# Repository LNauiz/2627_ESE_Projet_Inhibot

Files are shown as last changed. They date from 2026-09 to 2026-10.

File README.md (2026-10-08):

# 2627_ESE_Projet_Inhibot
_Projet réalisé par SERPHIN Bradley, NAVIZET Léonard et BOISBOURDIN Lucas_

---
## Présentation du projet
Le but du projet est de créer un petit robot autonome capable de récupérer des canettes en fonction de leur couleur, par exemple rouge ou verte, et de déposer ces canettes dans une zone définis à l'avance.

Architecture du projet :

Micro Controller

---

## Plan de la présentation
* [Conception du PCB](#conception-du-pcb)
* [Mécanique du robot](#mecanique-du-robot)
* [Code](#code)

---
## Conception du PCB
Pour la conception du PCB, plusieurs composants étaient recommandés :

- [Régulateur de tension 3.3V (BU)](https://github.com/LNauiz/2627_ESE_Projet_Inhibot/blob/main/Datasheet/Regulateur3-3V_buxxsd5wg-e.pdf)
- [Chargeur de batterie (BQ25896RTWR)](https://github.com/LNauiz/2627_ESE_Projet_Inhibot/blob/main/Datasheet/bq25896.pdf)
- [Jauge pour la batterie (BQ27220)](https://github.com/LNauiz/2627_ESE_Projet_Inhibot/blob/main/Datasheet/bq27220.pdf)
- [Driver de moteur (DRV8833PWR)](https://github.com/LNauiz/2627_ESE_Projet_Inhibot/blob/main/Datasheet/DriverMotoreducteur_drv8833.pdf)

En plus de ces composants recommandés nous avons ajouté les composants suivant :
- [STM32G431RBT6](https://github.com/LNauiz/2627_ESE_Projet_Inhibot/blob/main/Datasheet/stm32g431rbt6.pdf)
- [Accéléromètre et Gyroscope (LSM6DSLTR)](https://github.com/LNauiz/2627_ESE_Projet_Inhibot/blob/main/Datasheet/Accelerometre%26Gyroscope_LSM6DSLTR.pdf)

---
## Mécanique du robot
Pour réaliser la partie mécanique il fallait savoir quelle format de canette le robot doit récupérer. Le format choisis est le format "Sleek".

---
## Code

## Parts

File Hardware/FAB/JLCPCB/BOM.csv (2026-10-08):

Comment | Designator | Footprint | JLCPCB Part #
10pF | C202,C203 | Capacitor_SMD:C_0402_1005Metric | C32949
10n | C207,C403 | Capacitor_SMD:C_0402_1005Metric | C15195
47n | C304 | Capacitor_SMD:C_0402_1005Metric | C880605
100n | C201,C204,C205,C206,C209,C210,C301,C401,C402,C502,C503,C505,C506,C507,C508,C509,C510 | Capacitor_SMD:C_0402_1005Metric | C1525
470n | C302 | Capacitor_SMD:C_0603_1608Metric | C1623
1u | C311,C312,C314,C501,C504 | Capacitor_SMD:C_0402_1005Metric | C52923
1u | L301 |  | C84468
2.2u | C303,C404 | Capacitor_SMD:C_0402_1005Metric | C12530
4u7 | C208,C305 | Capacitor_SMD:C_0402_1005Metric | C23733
8.2u | C310 | Capacitor_SMD:C_1206_3216Metric | C2182568
10u | C306,C307,C308,C309,C405 | Capacitor_SMD:C_0402_1005Metric | C15525
470u | C406 | Capacitor_SMD:CP_Elec_10x10.5 | C178566
10m | R306 | Resistor_SMD:R_2512_6332Metric | C105142
200m | R404,R407 | Resistor_SMD:R_0805_2012Metric | C2074761
100 | R314 | Resistor_SMD:R_0402_1005Metric | C25076
470R | R308 | Resistor_SMD:R_0402_1005Metric | C25117
1k | R202,R203,R305,R401,R402,R403,R405,R406 | Resistor_SMD:R_0402_1005Metric | C11702
4.7k | R207,R208,R317 | Resistor_SMD:R_0402_1005Metric | C25900
5k1 | R302,R303,R312,R313 | Resistor_SMD:R_0402_1005Metric | C25905
10k | R307,R309,R310,R311,R315,R316,R408 | Resistor_SMD:R_0402_1005Metric | C25744
100k | R301,R304 | Resistor_SMD:R_0402_1005Metric | C25741
BQ25896RTWR | U302 | Package_DFN_QFN:Texas_RTW_WQFN-24-1EP_4x4mm_P0.5mm_EP2.7x2.7mm | C181475
BQ27220YZFR | U303 | Package_BGA:Texas_DSBGA-9_1.4715x1.4715mm_Layout3x3_P0.5mm | C528617
BU33SD5WG-TR | U305 | Package_TO_SOT_SMD:TSOT-23-5 | C3750265
Conn_ST_STDC14 | J201 | Connector_PinHeader_1.27mm:PinHeader_2x07_P1.27mm_Vertical_SMD | C3975190
DMN313DLT-7 | Q303 | Package_TO_SOT_SMD:SOT-523 | C155524
DMP1045U-7 | Q302 | Package_TO_SOT_SMD:SOT-23 | C177033
DRV8833PW-PR | U402 | Package_SO:TSSOP-16-1EP_4.4x5mm_P0.65mm_EP3x3mm | C50506
GREEN | D201 | LED_SMD:LED_0603_1608Metric | C12624
LSM6DSL | U401 | Package_LGA:LGA-14_3x2.5mm_P0.5mm_LayoutBorder3x4y | C126672
MMDT2222A | Q301 | Package_TO_SOT_SMD:SOT-363_SC-70-6 | C7603394
RED | D202 | LED_SMD:LED_0603_1608Metric | C2286
SN74AHCT1G125DBVR | U501 | Package_TO_SOT_SMD:SOT-23-5 | C20617903
STAT | D303 | LED_SMD:LED_0603_1608Metric | C111340
STM32G431RBT6 | U201 | Package_QFP:LQFP-64_10x10mm_P0.5mm | C431633
SW_Push | SW101,SW201 | Button_Switch_SMD:SW_Push_1P1T_NO_CK_KMR2 | C72443
USB_C_Receptacle_USB2.0_16P | J301 | Connector_USB:USB_C_Receptacle_GCT_USB4105-xx-A_16P_TopMnt_Horizontal | C2765186
USBLC6-2SC6 | U301 | Package_TO_SOT_SMD:SOT-23-6 | C7519
WS2812B | D502 | LED_SMD:LED_WS2812B-Mini_PLCC4_3.5x3.5mm | C52941386
X322516MLB4SI | Y201 | Crystal:Crystal_SMD_EuroQuartz_MT-4Pin_3.2x2.5mm | C13738
~{PG} | D302 | LED_SMD:LED_0603_1608Metric | C12624

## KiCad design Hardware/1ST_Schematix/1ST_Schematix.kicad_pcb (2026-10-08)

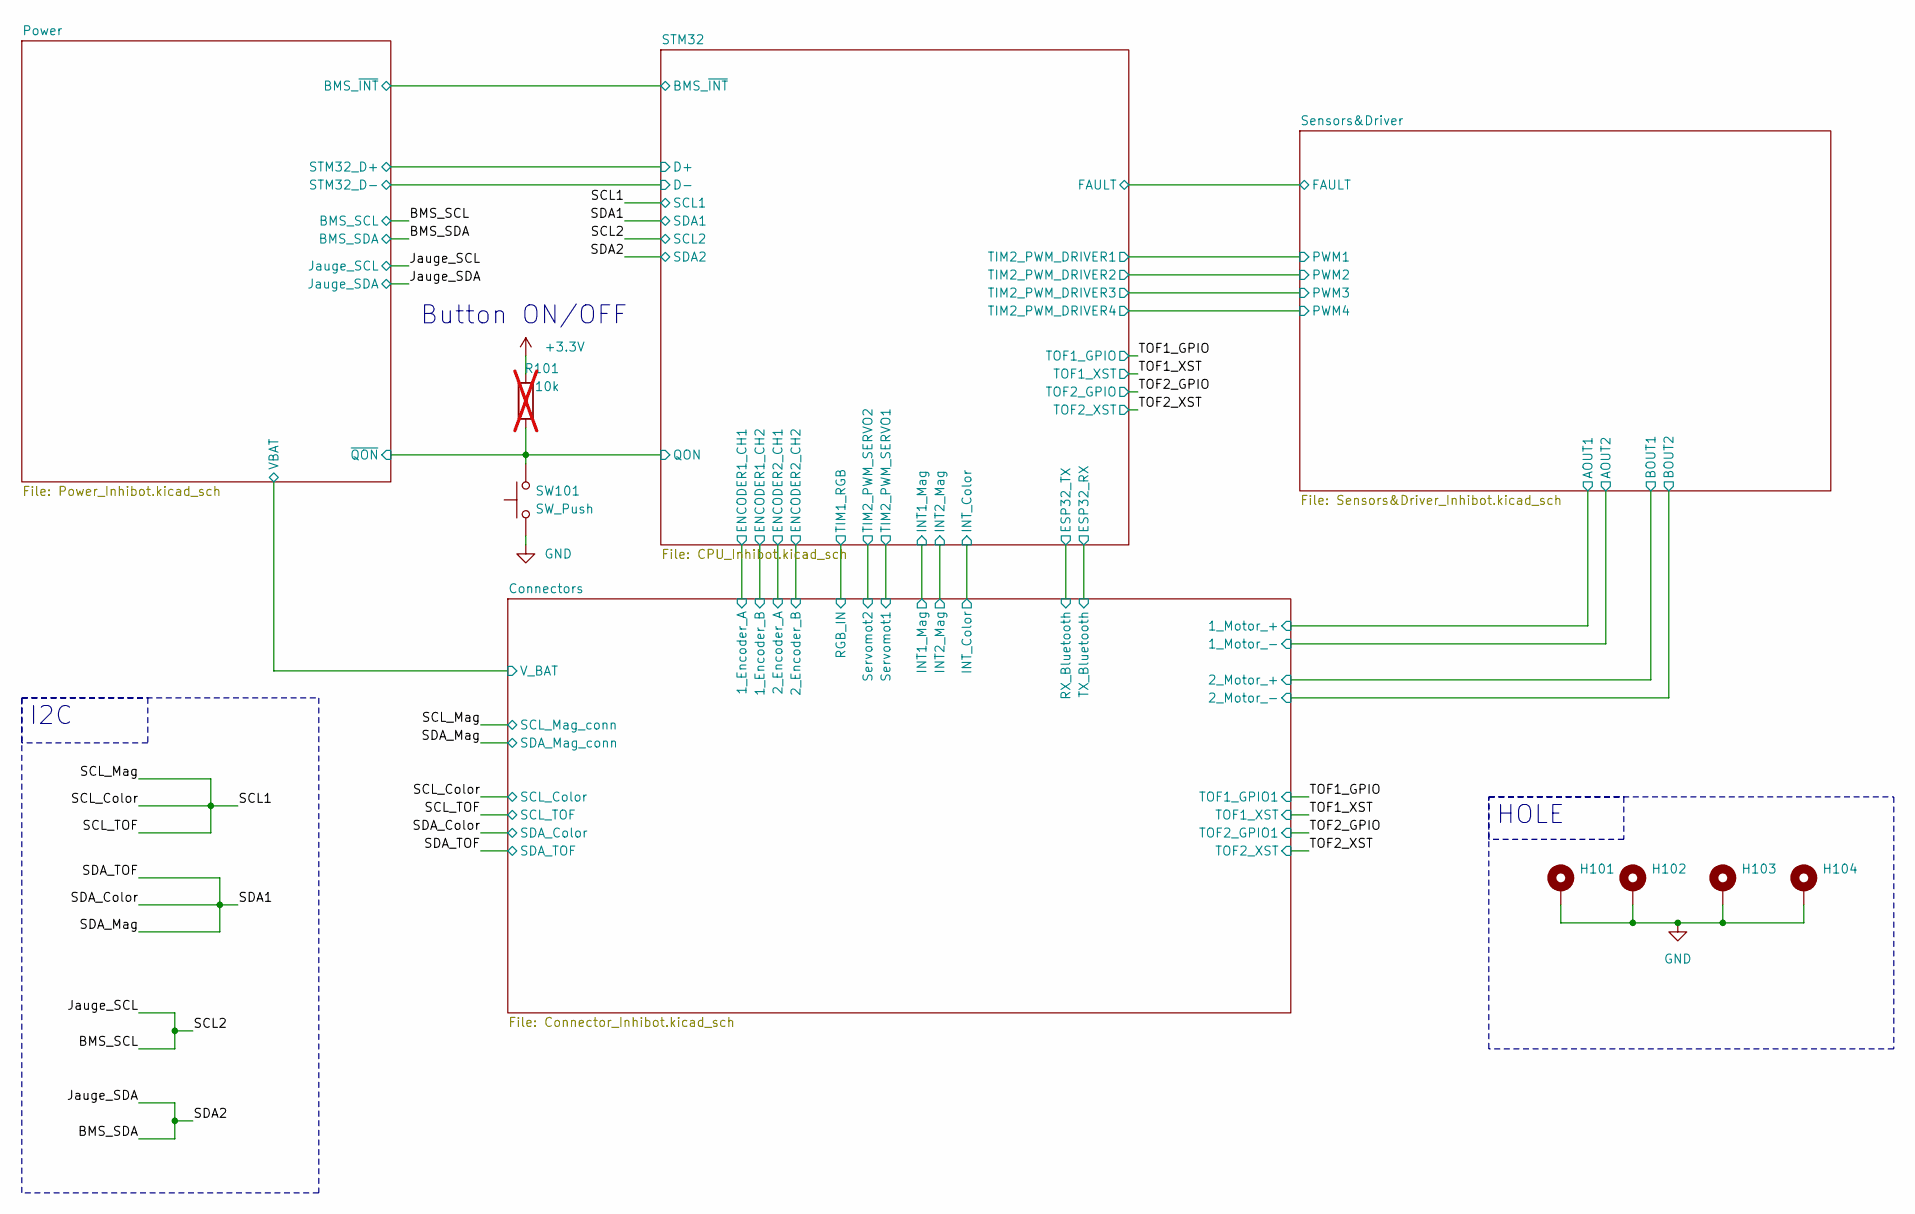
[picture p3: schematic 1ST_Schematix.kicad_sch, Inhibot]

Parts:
H101, H102, H103, H104: MountingHole_Pad; MountingHole_3.2mm_M3_ISO14580_Pad
R101: 10k; R_0603_1608Metric_Pad0.98x0.95mm_HandSolder; not fitted
SW101: SW_Push; SW_Push_1P1T_NO_CK_KMR2; JLCPCB Parts # C72443

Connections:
+3.3V: R101.1; also elsewhere on the board
/Power/~QON: R101.2, SW101.2; also elsewhere on the board
GND: H101.1 (1_1), H102.1 (1_1), H103.1 (1_1), H104.1 (1_1), SW101.1; also elsewhere on the board

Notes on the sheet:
Button ON/OFF
I2C
HOLE

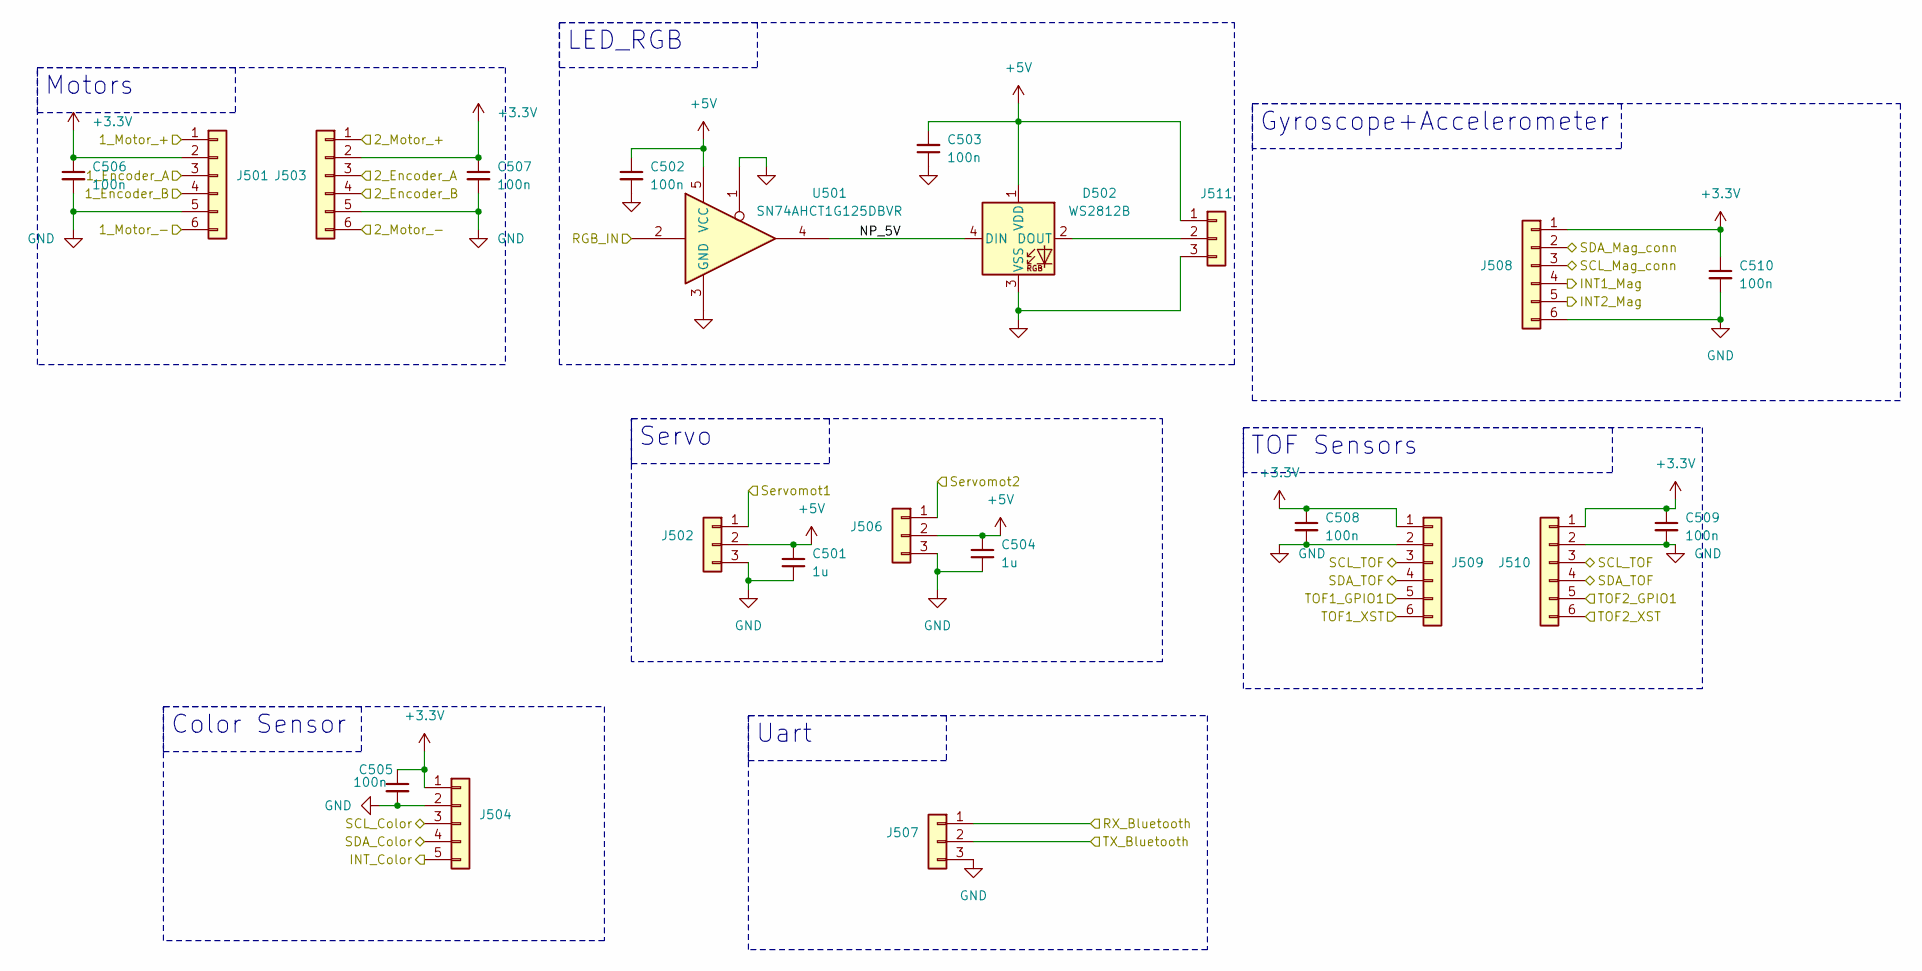
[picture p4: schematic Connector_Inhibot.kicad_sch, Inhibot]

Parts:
C501, C504: 1u; C_0402_1005Metric; JLCPCB Parts # C52923
C502, C503, C505, C506, C507, C508, C509, C510: 100n; C_0402_1005Metric; JLCPCB Parts # C1525
D502: WS2812B; LED_WS2812B-Mini_PLCC4_3.5x3.5mm; JLCPCB Parts # C52941386
J501, J503, J508, J509, J510: Conn_01x06; JST_EH_B6B-EH-A_1x06_P2.50mm_Vertical
J502, J506, J507, J511: Conn_01x03; JST_EH_B3B-EH-A_1x03_P2.50mm_Vertical
J504: Conn_01x05; JST_EH_B5B-EH-A_1x05_P2.50mm_Vertical
U501: SN74AHCT1G125DBVR; SOT-23-5; JLCPCB Parts # C20617903

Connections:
+3.3V: C505.1, C506.1, C507.1, C508.1, C509.1, C510.1, J501.2, J503.2, J504.1, J508.1, J509.1, J510.1; also elsewhere on the board
+5V: C501.1, C502.1, C503.2, C504.1, D502.1 (VDD), J502.2, J506.2, J511.1, U501.5 (VCC); also elsewhere on the board
/Connectors/1_Encoder_A: J501.3; also elsewhere on the board
/Connectors/1_Encoder_B: J501.4; also elsewhere on the board
/Connectors/1_Motor_+: J501.1; also elsewhere on the board
/Connectors/1_Motor_-: J501.6; also elsewhere on the board
/Connectors/2_Encoder_A: J503.3; also elsewhere on the board
/Connectors/2_Encoder_B: J503.4; also elsewhere on the board
/Connectors/2_Motor_+: J503.1; also elsewhere on the board
/Connectors/2_Motor_-: J503.6; also elsewhere on the board
/Connectors/INT1_Mag: J508.4; also elsewhere on the board
/Connectors/INT2_Mag: J508.5; also elsewhere on the board
/Connectors/INT_Color: J504.5; also elsewhere on the board
/Connectors/NP_5V: D502.4 (DIN), U501.4
/Connectors/RGB_IN: U501.2; also elsewhere on the board
/Connectors/RX_Bluetooth: J507.1; also elsewhere on the board
/Connectors/Servomot1: J502.1; also elsewhere on the board
/Connectors/Servomot2: J506.1; also elsewhere on the board
/Connectors/TX_Bluetooth: J507.2; also elsewhere on the board
/SCL1: J504.3, J508.3, J509.3, J510.3; also elsewhere on the board
/SDA1: J504.4, J508.2, J509.4, J510.4; also elsewhere on the board
/TOF1_GPIO: J509.5; also elsewhere on the board
/TOF1_XST: J509.6; also elsewhere on the board
/TOF2_GPIO: J510.5; also elsewhere on the board
/TOF2_XST: J510.6; also elsewhere on the board
GND: C501.2, C502.2, C503.1, C504.2, C505.2, C506.2, C507.2, C508.2, C509.2, C510.2, D502.3 (VSS), J501.5, J502.3, J503.5, J504.2, J506.3, J507.3, J508.6, J509.2, J510.2, J511.3, U501.1, U501.3 (GND); also elsewhere on the board
unnamed: D502.2 (DOUT), J511.2

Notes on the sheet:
Uart
LED_RGB
Servo
TOF Sensors
Color Sensor
Gyroscope+Accelerometer
Motors

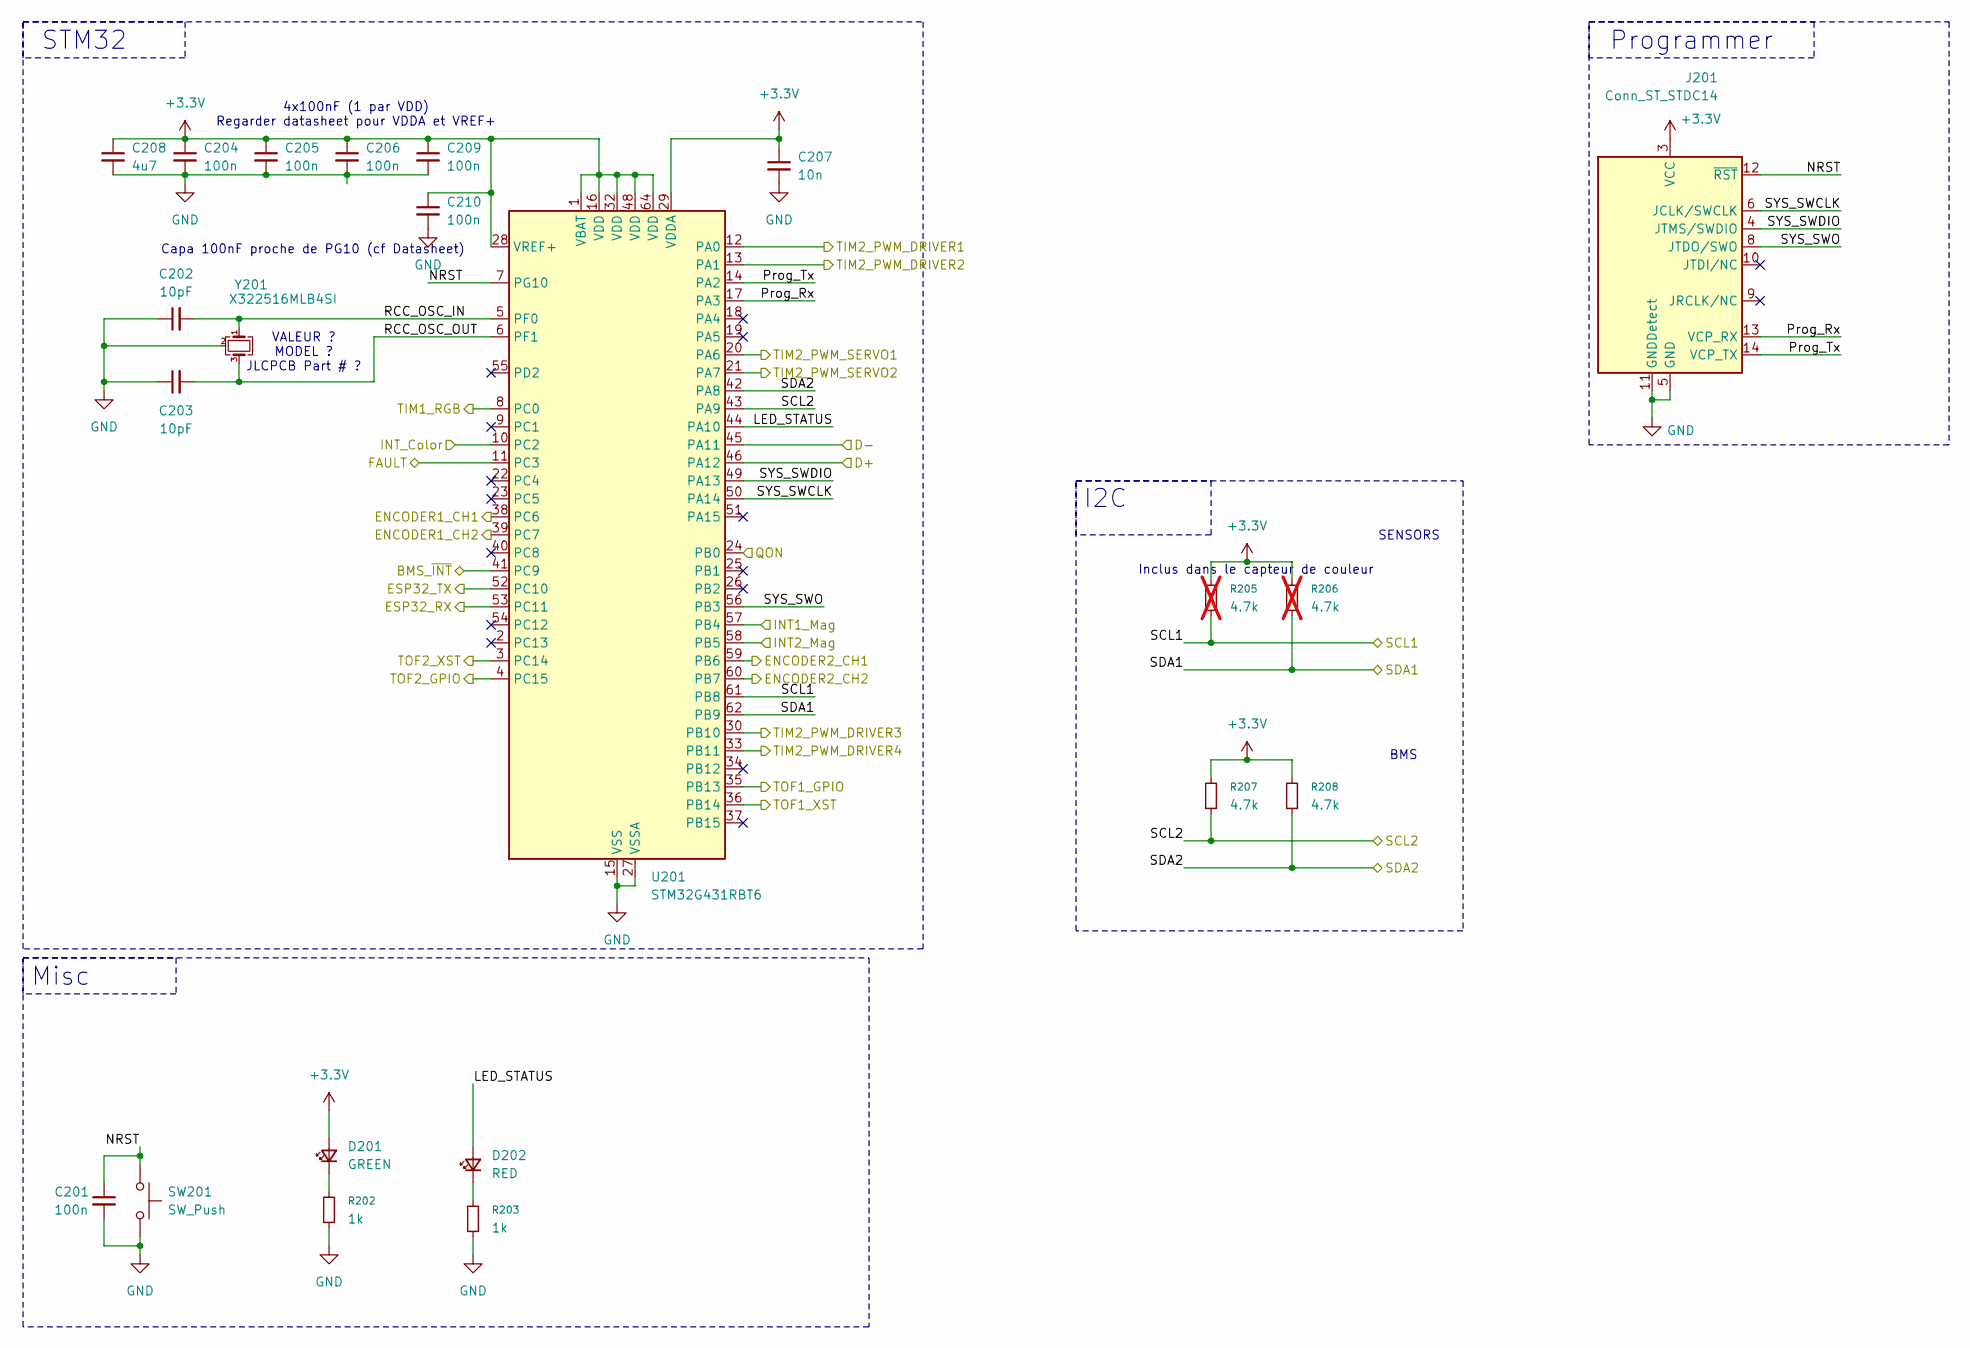
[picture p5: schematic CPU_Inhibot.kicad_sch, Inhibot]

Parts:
C201, C204, C205, C206, C209, C210: 100n; C_0402_1005Metric; JLCPCB Parts # C1525
C202, C203: 10pF; C_0402_1005Metric; JLCPCB Parts # C32949
C207: 10n; C_0402_1005Metric; JLCPCB Parts # C15195
C208: 4u7; C_0402_1005Metric; JLCPCB Parts # C23733
D201: GREEN; LED_0603_1608Metric; JLCPCB Parts # C12624
D202: RED; LED_0603_1608Metric; JLCPCB Parts # C2286
J201: Conn_ST_STDC14; PinHeader_2x07_P1.27mm_Vertical_SMD; JLCPCB Parts # C3975190
R202, R203: 1k; R_0402_1005Metric; JLCPCB Parts # C11702
R205, R206: 4.7k; R_0603_1608Metric_Pad0.98x0.95mm_HandSolder; not fitted
R207, R208: 4.7k; R_0402_1005Metric; JLCPCB Parts # C25900
SW201: SW_Push; SW_Push_1P1T_NO_CK_KMR2; MPN KSS221GLFS; JLCPCB Parts # C72443
U201: STM32G431RBT6; LQFP-64_10x10mm_P0.5mm; JLCPCB Parts # C431633
Y201: X322516MLB4SI; Crystal_SMD_EuroQuartz_MT-4Pin_3.2x2.5mm; JLCPCB Parts # C13738

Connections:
+3.3V: C204.1, C205.1, C206.1, C207.1, C208.1, C209.1, C210.1, D201.2 (A), J201.3 (VCC), R205.2, R206.2, R207.2, R208.2, U201.1 (VBAT), U201.16 (VDD), U201.28 (VREF+), U201.29 (VDDA), U201.32 (VDD), U201.48 (VDD), U201.64 (VDD); also elsewhere on the board
/BMS_SCL: R207.1, U201.43 (PA9); also elsewhere on the board
/BMS_SDA: R208.1, U201.42 (PA8); also elsewhere on the board
/Connectors/1_Encoder_A: U201.38 (PC6); also elsewhere on the board
/Connectors/1_Encoder_B: U201.39 (PC7); also elsewhere on the board
/Connectors/2_Encoder_A: U201.59 (PB6); also elsewhere on the board
/Connectors/2_Encoder_B: U201.60 (PB7); also elsewhere on the board
/Connectors/INT1_Mag: U201.57 (PB4); also elsewhere on the board
/Connectors/INT2_Mag: U201.58 (PB5); also elsewhere on the board
/Connectors/INT_Color: U201.10 (PC2); also elsewhere on the board
/Connectors/RGB_IN: U201.8 (PC0); also elsewhere on the board
/Connectors/RX_Bluetooth: U201.52 (PC10); also elsewhere on the board
/Connectors/Servomot1: U201.20 (PA6); also elsewhere on the board
/Connectors/Servomot2: U201.21 (PA7); also elsewhere on the board
/Connectors/TX_Bluetooth: U201.53 (PC11); also elsewhere on the board
/Power/BMS_~INT: U201.41 (PC9); also elsewhere on the board
/Power/STM32_D+: U201.46 (PA12); also elsewhere on the board
/Power/STM32_D-: U201.45 (PA11); also elsewhere on the board
/Power/~QON: U201.24 (PB0); also elsewhere on the board
/SCL1: R205.1, U201.61 (PB8); also elsewhere on the board
/SDA1: R206.1, U201.62 (PB9); also elsewhere on the board
/STM32/FAULT: U201.11 (PC3); also elsewhere on the board
/STM32/LED_STATUS: D202.2 (A), U201.44 (PA10)
/STM32/NRST: C201.1, J201.12 (~RST), SW201.1, U201.7 (PG10)
/STM32/Prog_Rx: J201.13 (VCP_RX), U201.17 (PA3)
/STM32/Prog_Tx: J201.14 (VCP_TX), U201.14 (PA2)
/STM32/RCC_OSC_IN: C202.2, U201.5 (PF0), Y201.1
/STM32/RCC_OSC_OUT: C203.2, U201.6 (PF1), Y201.3
/STM32/SYS_SWCLK: J201.6 (JCLK/SWCLK), U201.50 (PA14)
/STM32/SYS_SWDIO: J201.4 (JTMS/SWDIO), U201.49 (PA13)
/STM32/SYS_SWO: J201.8 (JTDO/SWO), U201.56 (PB3)
/STM32/TIM2_PWM_DRIVER1: U201.12 (PA0); also elsewhere on the board
/STM32/TIM2_PWM_DRIVER2: U201.13 (PA1); also elsewhere on the board
/STM32/TIM2_PWM_DRIVER3: U201.30 (PB10); also elsewhere on the board
/STM32/TIM2_PWM_DRIVER4: U201.33 (PB11); also elsewhere on the board
/TOF1_GPIO: U201.35 (PB13); also elsewhere on the board
/TOF1_XST: U201.36 (PB14); also elsewhere on the board
/TOF2_GPIO: U201.4 (PC15); also elsewhere on the board
/TOF2_XST: U201.3 (PC14); also elsewhere on the board
GND: C201.2, C202.1, C203.1, C204.2, C205.2, C206.2, C207.2, C208.2, C209.2, C210.2, J201.5 (GND), J201.7 (GND), J201.11 (GNDDetect), R202.1, R203.1, SW201.2, U201.15 (VSS), U201.27 (VSSA), U201.31 (VSS), U201.47 (VSS), U201.63 (VSS), Y201.2 (G), Y201.4 (G); also elsewhere on the board
unnamed: D201.1 (K), R202.2
unnamed: D202.1 (K), R203.2

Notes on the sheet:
STM32
Inclus dans le capteur de couleur
4x100nF (1 par VDD) Regarder datasheet pour VDDA et VREF+
SENSORS
Capa 100nF proche de PG10 (cf Datasheet)
BMS
Misc
Programmer
VALEUR ? MODEL ? JLCPCB Part # ?
I2C

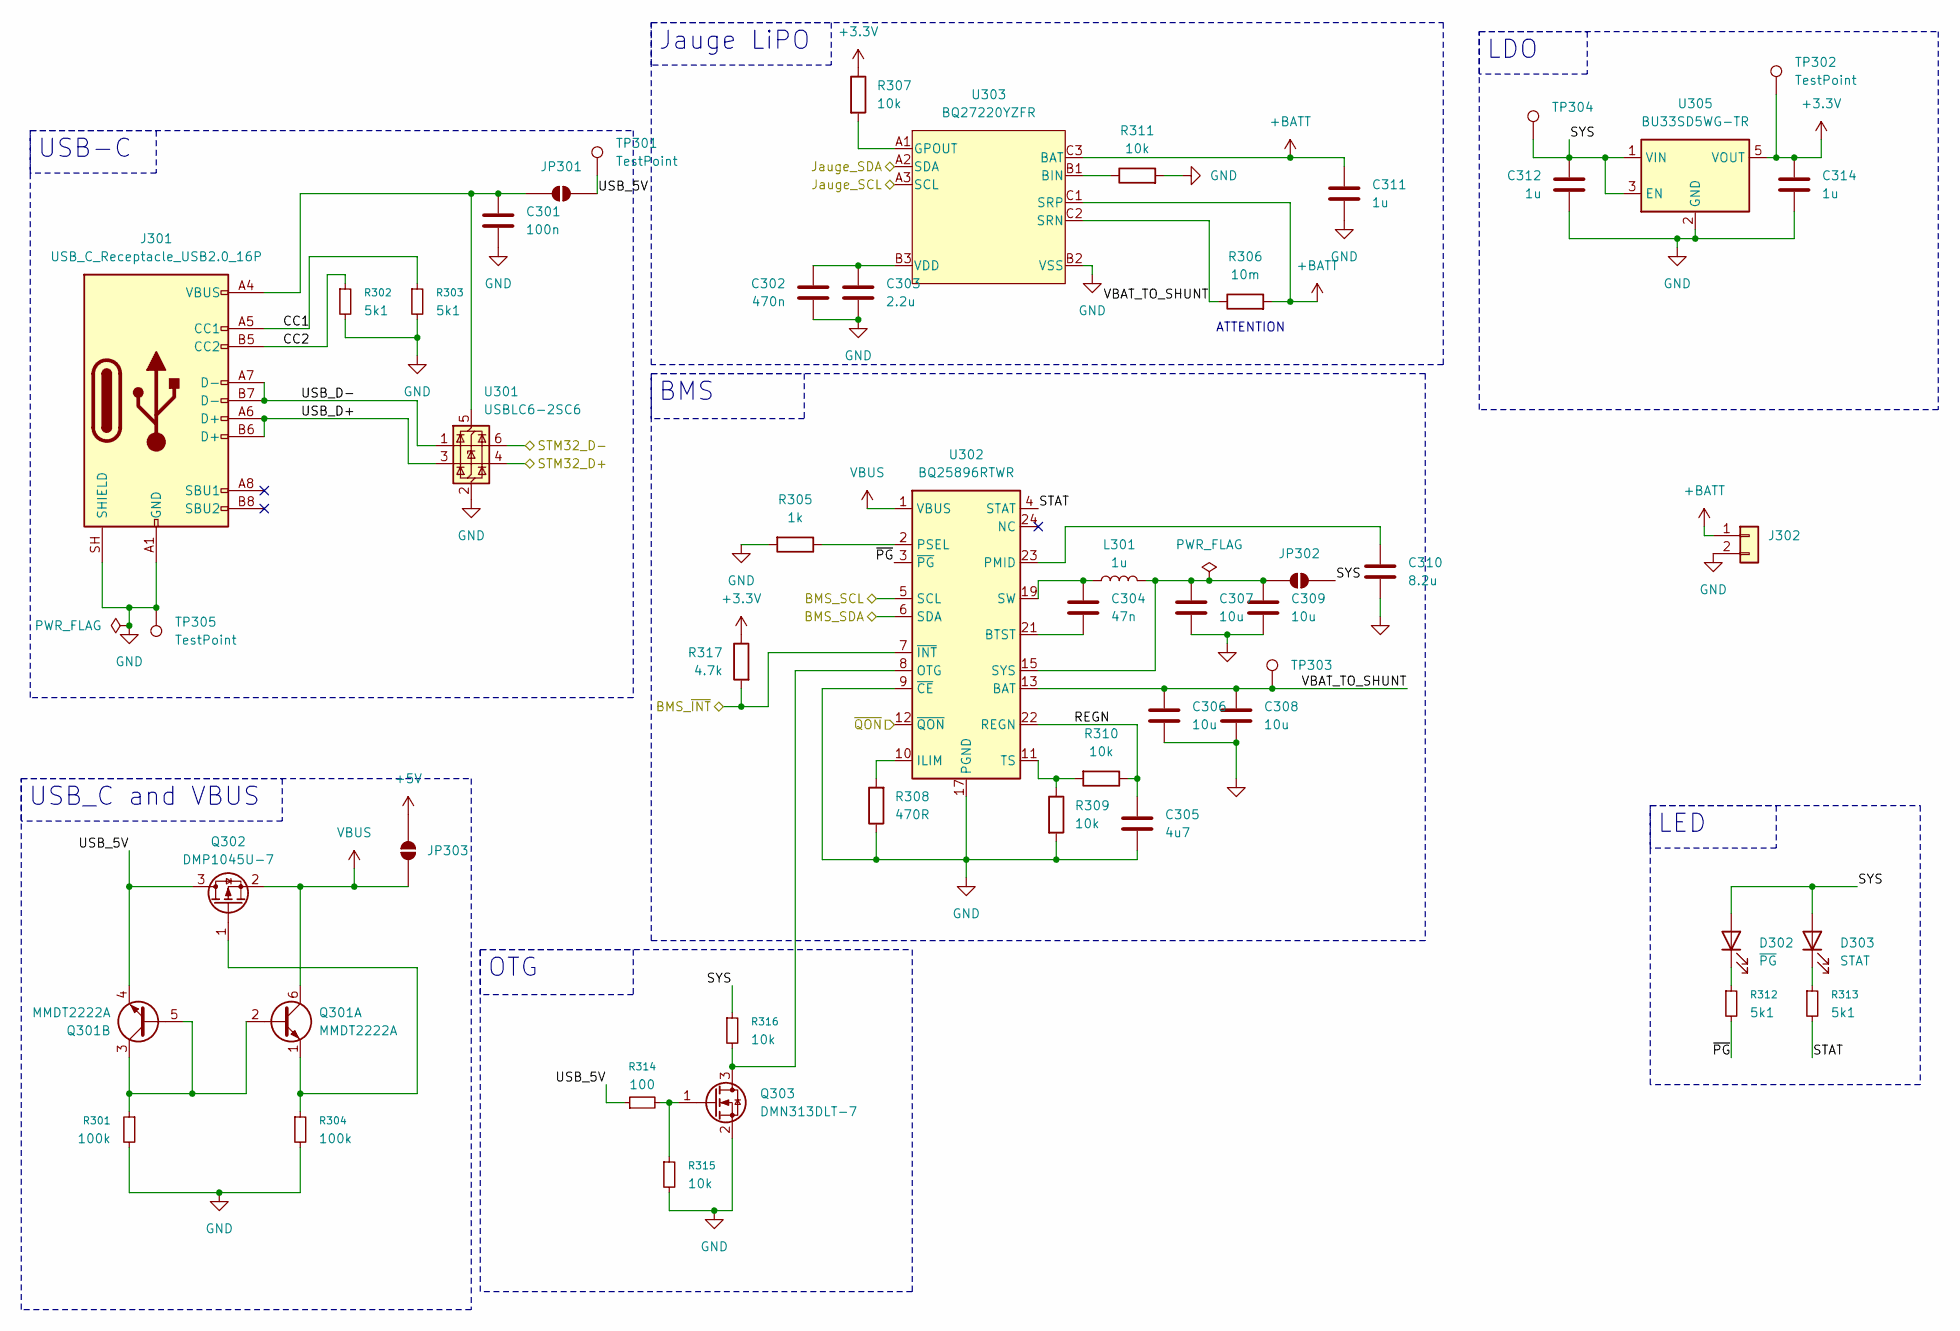
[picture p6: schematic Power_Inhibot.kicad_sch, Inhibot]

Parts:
C301: 100n; C_0402_1005Metric; JLCPCB Parts # C1525
C302: 470n; C_0603_1608Metric; JLCPCB Parts # C1623
C303: 2.2u; C_0402_1005Metric; JLCPCB Parts # C12530
C304: 47n; C_0402_1005Metric; JLCPCB Parts # C880605
C305: 4u7; C_0402_1005Metric; JLCPCB Parts # C23733
C306, C307, C308, C309: 10u; C_0402_1005Metric; JLCPCB Parts # C15525
C310: 8.2u; C_1206_3216Metric; JLCPCB Parts # C2182568
C311, C312, C314: 1u; C_0402_1005Metric; JLCPCB Parts # C52923
D302: ~{PG}; LED_0603_1608Metric; JLCPCB Parts # C12624
D303: STAT; LED_0603_1608Metric; JLCPCB Parts # C111340
J301: USB_C_Receptacle_USB2.0_16P; USB_C_Receptacle_GCT_USB4105-xx-A_16P_TopMnt_Horizontal; JLCPCB Parts # C2765186
J302: Conn_01x02; JST_EH_B2B-EH-A_1x02_P2.50mm_Vertical
JP301, JP302, JP303: SolderJumper_2_Open; SolderJumper-2_P1.3mm_Open_TrianglePad1.0x1.5mm
L301: 1u; JLCPCB Parts # C84468
Q301: MMDT2222A; SOT-363_SC-70-6; JLCPCB Parts # C7603394
Q302: DMP1045U-7; SOT-23; JLCPCB Parts # C177033
Q303: DMN313DLT-7; SOT-523; JLCPCB Parts # C155524
R301, R304: 100k; R_0402_1005Metric; JLCPCB Parts # C25741
R302, R303, R312, R313: 5k1; R_0402_1005Metric; JLCPCB Parts # C25905
R305: 1k; R_0402_1005Metric; JLCPCB Parts # C11702
R306: 10m; R_2512_6332Metric; JLCPCB Parts # C105142
R307, R309, R310, R311, R315, R316: 10k; R_0402_1005Metric; JLCPCB Parts # C25744
R308: 470R; R_0402_1005Metric; JLCPCB Parts # C25117
R314: 100; R_0402_1005Metric; JLCPCB Parts # C25076
R317: 4.7k; R_0402_1005Metric; JLCPCB Parts # C25900
TP301, TP302, TP303, TP304, TP305: TestPoint; TestPoint_Pad_D2.0mm
U301: USBLC6-2SC6; SOT-23-6; JLCPCB Parts # C7519
U302: BQ25896RTWR; Texas_RTW_WQFN-24-1EP_4x4mm_P0.5mm_EP2.7x2.7mm; JLCPCB Parts # C181475
U303: BQ27220YZFR; Texas_DSBGA-9_1.4715x1.4715mm_Layout3x3_P0.5mm; JLCPCB Parts # C528617
U305: BU33SD5WG-TR; TSOT-23-5; JLCPCB Parts # C3750265

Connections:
+3.3V: C314.1, R307.1, R317.1, TP302.1 (1_1), U305.5 (VOUT); also elsewhere on the board
+5V: JP303.2 (B); also elsewhere on the board
+BATT: C311.1, J302.1, R306.2, U303.C1 (SRP), U303.C3 (BAT)
/BMS_SCL: U302.5 (SCL), U303.A3 (SCL); also elsewhere on the board
/BMS_SDA: U302.6 (SDA), U303.A2 (SDA); also elsewhere on the board
/Power/BMS_~INT: R317.2, U302.7 (~INT); also elsewhere on the board
/Power/CC1: J301.A5 (CC1), R303.1
/Power/CC2: J301.B5 (CC2), R302.1
/Power/REGN: C305.2, R310.1, U302.22 (REGN)
/Power/STAT: R313.2, U302.4 (STAT)
/Power/STM32_D+: U301.4 (I/O2); also elsewhere on the board
/Power/STM32_D-: U301.6 (I/O1); also elsewhere on the board
/Power/SYS: C312.1, D302.2 (A), D303.2 (A), JP302.2 (B), R316.1, TP304.1 (1_1), U305.1 (VIN), U305.3 (EN)
/Power/USB_5V: JP301.2 (B), Q301.4 (E2), Q302.3 (D), R314.1, TP301.1 (1_1)
/Power/USB_D+: J301.A6 (D+), J301.B6 (D+), U301.3 (I/O2)
/Power/USB_D-: J301.A7 (D-), J301.B7 (D-), U301.1 (I/O1)
/Power/VBAT_TO_SHUNT: C306.1, C308.1, R306.1, TP303.1 (1_1), U302.13 (BAT), U302.14 (BAT), U303.C2 (SRN)
/Power/~PG: R312.2, U302.3 (~PG)
/Power/~QON: U302.12 (~QON); also elsewhere on the board
GND: C301.2, C302.2, C303.2, C305.1, C306.2, C307.2, C308.2, C309.2, C310.2, C311.2, C312.2, C314.2, J301.A1 (GND), J301.A12 (GND), J301.B1 (GND), J301.B12 (GND), J301.SH (SHIELD), J302.2, Q303.2 (S), R301.2, R302.2, R303.2, R304.2, R305.2, R308.1, R309.2, R311.2, R315.2, TP305.1 (1_1), U301.2 (GND), U302.9 (~CE), U302.17 (PGND), U302.18 (PGND), U302.25 (PGND), U303.B2 (VSS), U305.2 (GND); also elsewhere on the board
unnamed: C304.2, L301.1, U302.19 (SW), U302.20 (SW)
unnamed: D302.1 (K), R312.1
unnamed: D303.1 (K), R313.1
unnamed: C301.1, J301.A4 (VBUS), J301.A9 (VBUS), J301.B4 (VBUS), J301.B9 (VBUS), JP301.1 (A), U301.5 (VBUS)
unnamed: C307.1, C309.1, JP302.1 (A), L301.2, U302.15 (SYS), U302.16 (SYS)
unnamed: Q301.2 (B1), Q301.3 (C2), Q301.5 (B2), R301.1
unnamed: Q301.1 (E1), Q302.1 (G), R304.1
unnamed: Q303.3 (D), R316.2, U302.8 (OTG)
unnamed: Q303.1 (G), R314.2, R315.1
unnamed: C304.1, U302.21 (BTST)
unnamed: R308.2, U302.10 (ILIM)
unnamed: C310.1, U302.23 (PMID)
unnamed: R305.1, U302.2 (PSEL)
unnamed: R309.1, R310.2, U302.11 (TS)
unnamed: R311.1, U303.B1 (BIN)
unnamed: R307.2, U303.A1 (GPOUT)
unnamed: C302.1, C303.1, U303.B3 (VDD)
VBUS: JP303.1 (A), Q301.6 (C1), Q302.2 (S), U302.1 (VBUS)

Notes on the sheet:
ATTENTION
LED
OTG
LDO
Jauge LiPO
USB-C
BMS
USB_C and VBUS

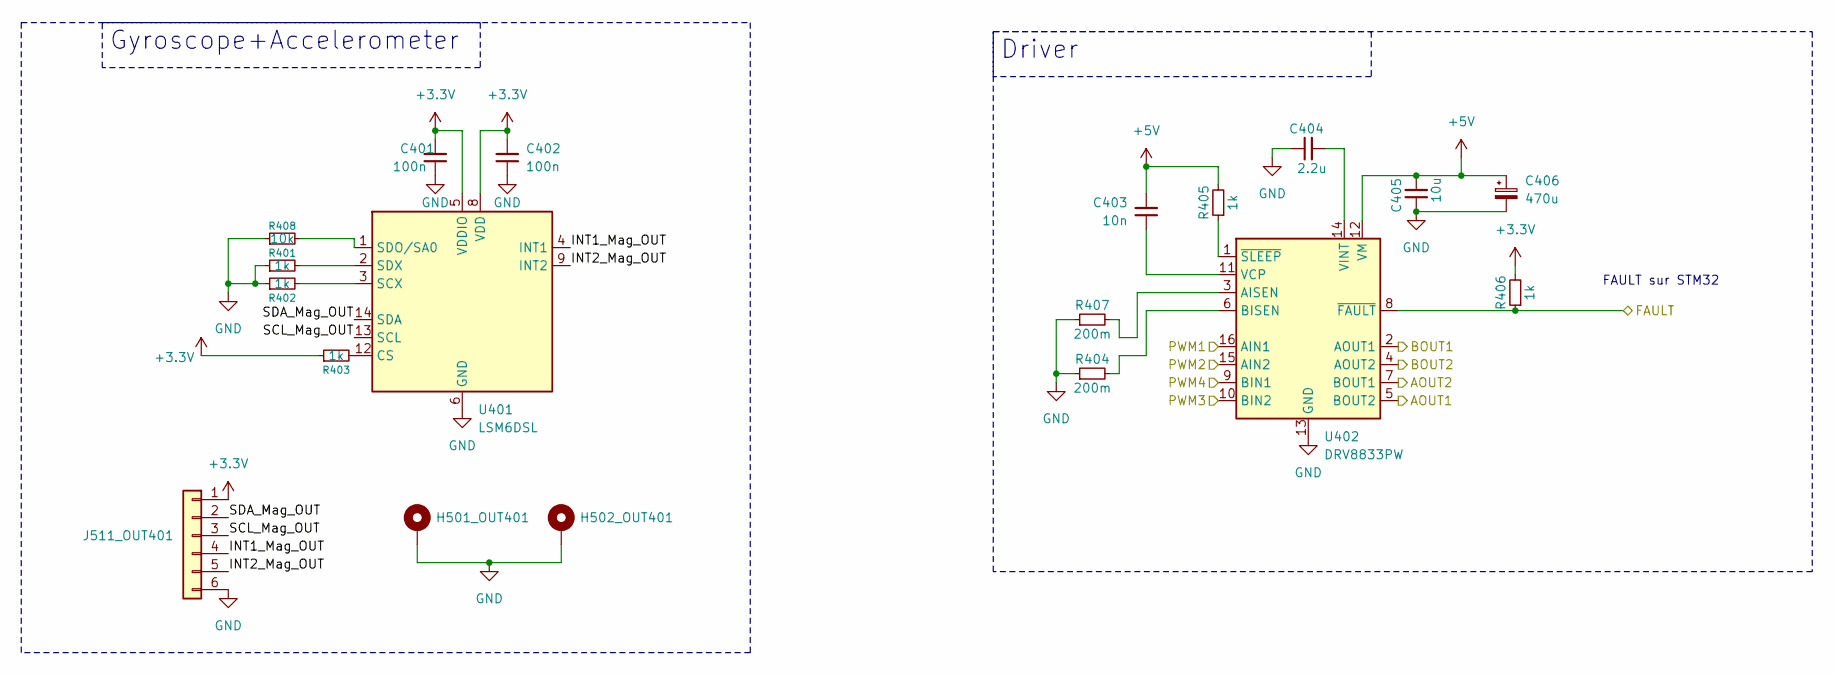
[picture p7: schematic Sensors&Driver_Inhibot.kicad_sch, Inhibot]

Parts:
C401, C402: 100n; C_0402_1005Metric; JLCPCB Part # C1525
C403: 10n; C_0402_1005Metric
C404: 2.2u; C_0402_1005Metric
C405: 10u; C_0402_1005Metric
C406: 470u; CP_Elec_10x10.5; JLCPCB Part # C178566
H501_OUT401, H502_OUT401: MountingHole_Pad; MountingHole_3.2mm_M3_ISO14580_Pad
J511_OUT401: Conn_01x06; JST_EH_B6B-EH-A_1x06_P2.50mm_Vertical
R401, R402, R403, R405, R406: 1k; R_0402_1005Metric
R404, R407: 200m; R_0805_2012Metric; JLCPCB Part # C2074761
R408: 10k; R_0402_1005Metric
U401: LSM6DSL; LGA-14_3x2.5mm_P0.5mm_LayoutBorder3x4y; JLCPCB Parts C126672
U402: DRV8833PW; TSSOP-16_4.4x5mm_P0.65mm

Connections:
+3.3V: C401.1, C402.1, J511_OUT401.1, R403.1, R406.2, U401.5 (VDDIO), U401.8 (VDD); also elsewhere on the board
+5V: C403.2, C405.2, C406.1, R405.2, U402.12 (VM); also elsewhere on the board
/Connectors/1_Motor_+: U402.5 (BOUT2); also elsewhere on the board
/Connectors/1_Motor_-: U402.7 (BOUT1); also elsewhere on the board
/Connectors/2_Motor_+: U402.2 (AOUT1); also elsewhere on the board
/Connectors/2_Motor_-: U402.4 (AOUT2); also elsewhere on the board
/STM32/FAULT: R406.1, U402.8 (~FAULT); also elsewhere on the board
/STM32/TIM2_PWM_DRIVER1: U402.16 (AIN1); also elsewhere on the board
/STM32/TIM2_PWM_DRIVER2: U402.15 (AIN2); also elsewhere on the board
/STM32/TIM2_PWM_DRIVER3: U402.10 (BIN2); also elsewhere on the board
/STM32/TIM2_PWM_DRIVER4: U402.9 (BIN1); also elsewhere on the board
/Sensors&Driver/INT1_Mag_OUT: J511_OUT401.4, U401.4 (INT1)
/Sensors&Driver/INT2_Mag_OUT: J511_OUT401.5, U401.9 (INT2)
/Sensors&Driver/SCL_Mag_OUT: J511_OUT401.3, U401.13 (SCL)
/Sensors&Driver/SDA_Mag_OUT: J511_OUT401.2, U401.14 (SDA)
GND: C401.2, C402.2, C404.1, C405.1, C406.2, H501_OUT401.1 (1_1), H502_OUT401.1 (1_1), J511_OUT401.6, R401.1, R402.1, R404.1, R407.1, R408.1, U401.6 (GND), U401.7 (GND), U402.13 (GND); also elsewhere on the board
unnamed: R403.2, U401.12 (CS)
unnamed: R402.2, U401.3 (SCX)
unnamed: R408.2, U401.1 (SDO/SA0)
unnamed: R401.2, U401.2 (SDX)
unnamed: R407.2, U402.3 (AISEN)
unnamed: R404.2, U402.6 (BISEN)
unnamed: C403.1, U402.11 (VCP)
unnamed: C404.2, U402.14 (VINT)
unnamed: R405.1, U402.1 (~SLEEP)

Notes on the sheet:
FAULT sur STM32
Driver
Gyroscope+Accelerometer

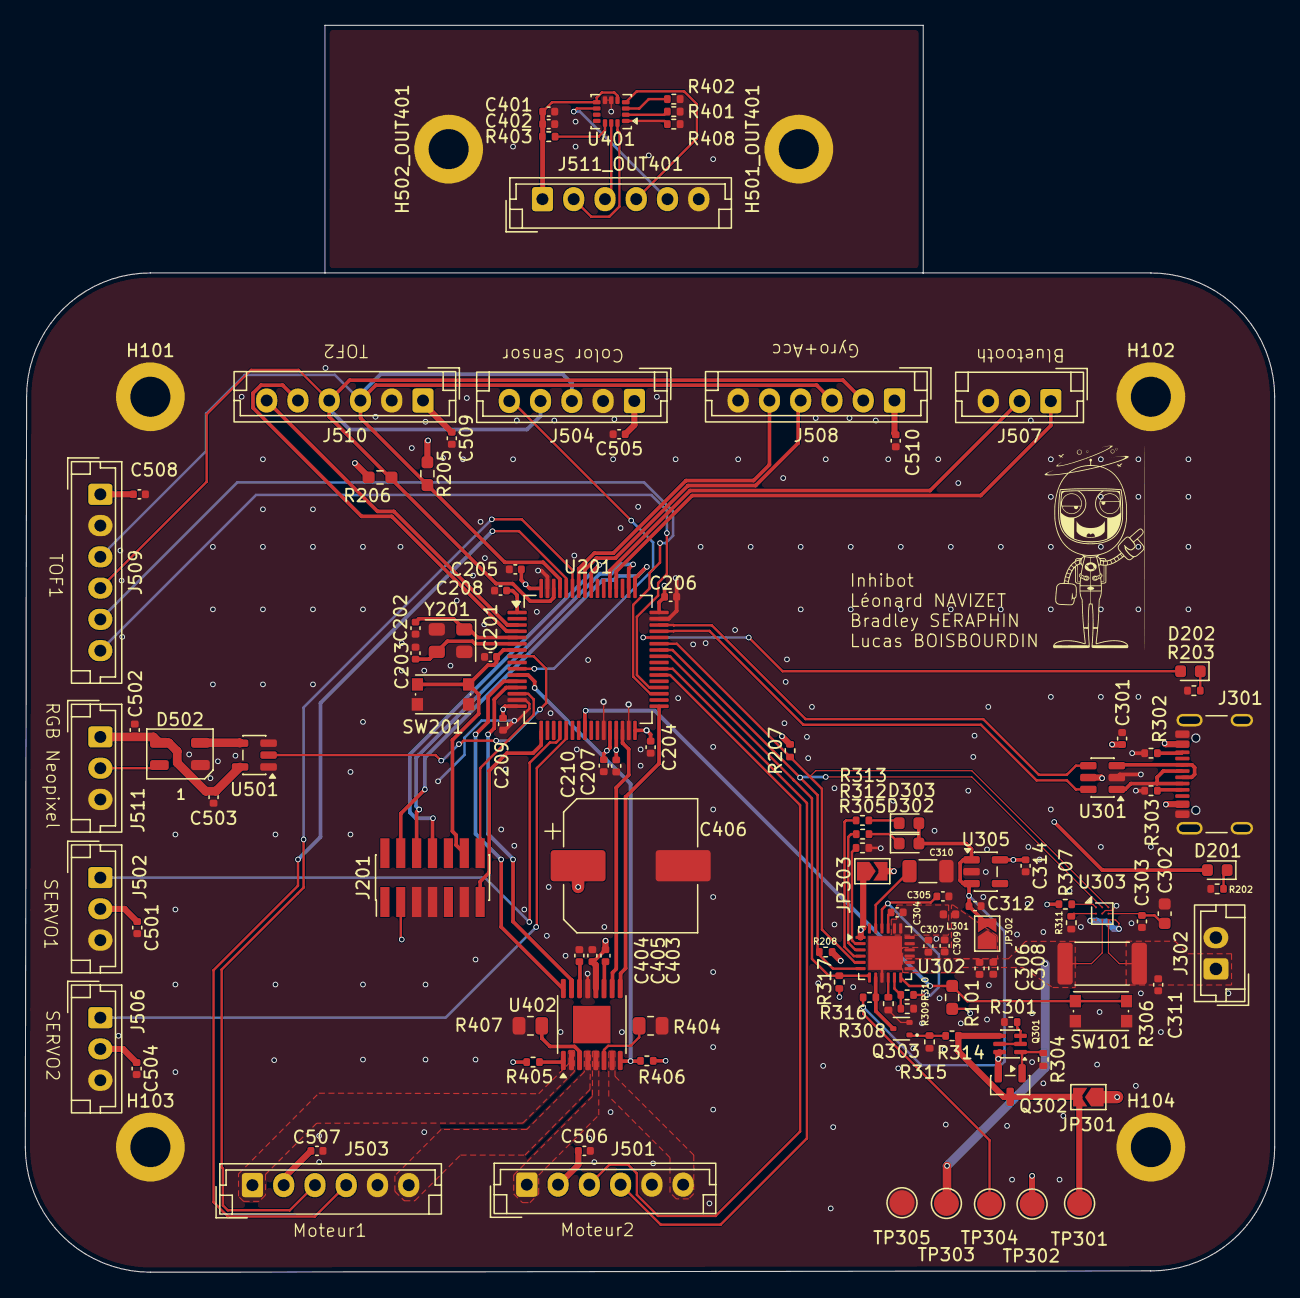
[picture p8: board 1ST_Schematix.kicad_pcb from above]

Board: 4 copper layers, 99.9 x 79.9 mm, 119 parts (0 on the bottom side), 91 nets.

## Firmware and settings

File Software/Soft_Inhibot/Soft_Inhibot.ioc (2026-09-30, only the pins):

Mcu.UserName=STM32G431RBTx
PA0.GPIO_Label=PWM_Driver_1
PA0.Signal=S_TIM2_CH1
PA1.GPIO_Label=PWM_Driver_2
PA1.Signal=S_TIM2_CH2
PA10.GPIO_Label=LED_STATUS
PA10.Signal=GPIO_Output
PA11.Signal=USB_DM
PA12.Signal=USB_DP
PA13.Signal=SYS_JTMS-SWDIO
PA14.Signal=SYS_JTCK-SWCLK
PA2.GPIO_Label=Prog_Tx
PA2.Signal=USART2_TX
PA3.GPIO_Label=Prog_Rx
PA3.Signal=USART2_RX
PA6.GPIO_Label=PWM_Servo
PA6.Signal=S_TIM3_CH1
PA7.GPIO_Label=PWM_Servo2
PA7.Signal=S_TIM3_CH2
PA8.GPIO_Label=BATTERY_I2C_SDA
PA8.Signal=I2C2_SDA
PA9.GPIO_Label=BATTERY_I2C_SCL
PA9.Signal=I2C2_SCL
PB0.GPIO_Label=QON
PB0.Signal=GPXTI0
PB10.GPIO_Label=PWM_Driver_3
PB10.Signal=S_TIM2_CH3
PB11.GPIO_Label=PWM_Driver_4
PB11.Signal=S_TIM2_CH4
PB13.GPIO_Label=TOF1_GPIO
PB13.Signal=GPXTI13
PB14.GPIO_Label=TOF1_XST
PB14.Signal=GPIO_Output
PB3.Signal=SYS_JTDO-SWO
PB4.GPIO_Label=INT1_Mag
PB4.Signal=GPXTI4
PB5.GPIO_Label=INT2_Mag
PB5.Signal=GPXTI5
PB6.GPIO_Label=ENCODER2_CH1
PB6.Signal=S_TIM4_CH1
PB7.GPIO_Label=ENCODER2_CH2
PB7.Signal=S_TIM4_CH2
PB8-BOOT0.GPIO_Label=SENSOR_I2C_SCL
PB8-BOOT0.Signal=I2C1_SCL
PB9.GPIO_Label=SENSOR_I2C_SDA
PB9.Signal=I2C1_SDA
PC0.GPIO_Label=TIM_RGB
PC0.Signal=S_TIM1_CH1
PC10.GPIO_Label=ESP32_TX
PC10.Signal=UART4_TX
PC11.GPIO_Label=ESP32_RX
PC11.Signal=UART4_RX
PC14-OSC32_IN.GPIO_Label=TOF2_XST
PC14-OSC32_IN.Signal=GPIO_Output
PC15-OSC32_OUT.GPIO_Label=TOF2_GPIO
PC15-OSC32_OUT.Signal=GPXTI15
PC2.GPIO_Label=INT_Color
PC2.Signal=GPXTI2
PC3.GPIO_Label=FAULT
PC3.Signal=GPXTI3
PC6.GPIO_Label=ENCODER1_CH2
PC6.Signal=S_TIM8_CH1
PC7.GPIO_Label=ENCODER1_CH1
PC7.Signal=S_TIM8_CH2
PC9.GPIO_Label=BMS_INT
PC9.Signal=GPXTI9
PF0-OSC_IN.Signal=RCC_OSC_IN
PF1-OSC_OUT.Signal=RCC_OSC_OUT

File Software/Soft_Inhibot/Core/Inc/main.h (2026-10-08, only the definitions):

#define TOF2_XST_Pin GPIO_PIN_14
#define TOF2_XST_GPIO_Port GPIOC
#define TOF2_GPIO_Pin GPIO_PIN_15
#define TOF2_GPIO_GPIO_Port GPIOC
#define TIM_RGB_Pin GPIO_PIN_0
#define TIM_RGB_GPIO_Port GPIOC
#define INT_Color_Pin GPIO_PIN_2
#define INT_Color_GPIO_Port GPIOC
#define FAULT_Pin GPIO_PIN_3
#define FAULT_GPIO_Port GPIOC
#define PWM_Driver_1_Pin GPIO_PIN_0
#define PWM_Driver_1_GPIO_Port GPIOA
#define PWM_Driver_2_Pin GPIO_PIN_1
#define PWM_Driver_2_GPIO_Port GPIOA
#define Prog_Tx_Pin GPIO_PIN_2
#define Prog_Tx_GPIO_Port GPIOA
#define Prog_Rx_Pin GPIO_PIN_3
#define Prog_Rx_GPIO_Port GPIOA
#define PWM_Servo_Pin GPIO_PIN_6
#define PWM_Servo_GPIO_Port GPIOA
#define PWM_Servo2_Pin GPIO_PIN_7
#define PWM_Servo2_GPIO_Port GPIOA
#define QON_Pin GPIO_PIN_0
#define QON_GPIO_Port GPIOB
#define PWM_Driver_3_Pin GPIO_PIN_10
#define PWM_Driver_3_GPIO_Port GPIOB
#define PWM_Driver_4_Pin GPIO_PIN_11
#define PWM_Driver_4_GPIO_Port GPIOB
#define TOF1_GPIO_Pin GPIO_PIN_13
#define TOF1_GPIO_GPIO_Port GPIOB
#define TOF1_XST_Pin GPIO_PIN_14
#define TOF1_XST_GPIO_Port GPIOB
#define ENCODER1_CH2_Pin GPIO_PIN_6
#define ENCODER1_CH2_GPIO_Port GPIOC
#define ENCODER1_CH1_Pin GPIO_PIN_7
#define ENCODER1_CH1_GPIO_Port GPIOC
#define BMS_INT_Pin GPIO_PIN_9
#define BMS_INT_GPIO_Port GPIOC
#define BATTERY_I2C_SDA_Pin GPIO_PIN_8
#define BATTERY_I2C_SDA_GPIO_Port GPIOA
#define BATTERY_I2C_SCL_Pin GPIO_PIN_9
#define BATTERY_I2C_SCL_GPIO_Port GPIOA
#define LED_STATUS_Pin GPIO_PIN_10
#define LED_STATUS_GPIO_Port GPIOA
#define ESP32_TX_Pin GPIO_PIN_10
#define ESP32_TX_GPIO_Port GPIOC
#define ESP32_RX_Pin GPIO_PIN_11
#define ESP32_RX_GPIO_Port GPIOC
#define INT1_Mag_Pin GPIO_PIN_4
#define INT1_Mag_GPIO_Port GPIOB
#define INT2_Mag_Pin GPIO_PIN_5
#define INT2_Mag_GPIO_Port GPIOB
#define ENCODER2_CH1_Pin GPIO_PIN_6
#define ENCODER2_CH1_GPIO_Port GPIOB
#define ENCODER2_CH2_Pin GPIO_PIN_7
#define ENCODER2_CH2_GPIO_Port GPIOB
#define SENSOR_I2C_SCL_Pin GPIO_PIN_8
#define SENSOR_I2C_SCL_GPIO_Port GPIOB
#define SENSOR_I2C_SDA_Pin GPIO_PIN_9
#define SENSOR_I2C_SDA_GPIO_Port GPIOB

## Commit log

2026-09-17 Créa de soft
    [1ST_Schematix.kicad_sch]
2026-09-17 power schematic
    [1ST_Schematix.kicad_sch, Power_Inhibot.kicad_sch]
2026-09-17 Datasheet et Schematix
    [1ST_Schematix.kicad_sch, CPU_Inhibot.kicad_sch, Power_Inhibot.kicad_sch]
2026-09-17 fin de séance
2026-09-17 stm pinout
    [CPU_Inhibot.kicad_sch]
2026-09-18 PCB POWER
    [Power_Inhibot.kicad_sch]
2026-09-18 modification ioc et UC
    [CPU_Inhibot.kicad_sch]
2026-09-18 Sensor PCB
    [Sensor_Inhibot.kicad_sch]
2026-09-18 Update Power
    [CPU_Inhibot.kicad_sch, Power_Inhibot.kicad_sch]
2026-09-18 more modif
    [CPU_Inhibot.kicad_sch]
2026-09-21 Update KiCad + Création Soft_Inhibot.ioc
    Soft_Inhibot est mieux que juste Software. C'est mon avis...
    [1ST_Schematix.kicad_sch, CPU_Inhibot.kicad_sch, Connector_Inhibot.kicad_sch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]
2026-09-21 Update PCB
    [1ST_Schematix.kicad_sch, CPU_Inhibot.kicad_sch, Connector_Inhibot.kicad_sch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]
2026-09-24 Power Update Kicad
    [Power_Inhibot.kicad_sch]
2026-09-24 nom des compo
    [1ST_Schematix.kicad_sch, CPU_Inhibot.kicad_sch, Connector_Inhibot.kicad_sch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]
2026-09-24 Bus I2C2
    [CPU_Inhibot.kicad_sch, Connector_Inhibot.kicad_sch, Power_Inhibot.kicad_sch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]
2026-09-24 Schematik Update
    [Power_Inhibot.kicad_sch]
2026-09-24 Update before INT
    [1ST_Schematix.kicad_sch, CPU_Inhibot.kicad_sch, Connector_Inhibot.kicad_sch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]
2026-09-30 Update KiCad and STM32CubeMX
    Ready for the check-in
    [1ST_Schematix.kicad_sch, CPU_Inhibot.kicad_sch, Connector_Inhibot.kicad_sch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]
2026-09-30 Update Schematic
    [Power_Inhibot.kicad_sch]
2026-09-30 schematic review with esteemed professor
    [1ST_Schematix.kicad_sch, 1st_schematic.kicad_pcb, 1st_schematic.kicad_sch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]
2026-09-30 prints for component except 10mOhm
    [CPU_Inhibot.kicad_sch, Connector_Inhibot.kicad_sch, Power_Inhibot.kicad_sch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]
2026-09-30 all footprints done
    [1ST_Schematix.kicad_sch, CPU_Inhibot.kicad_sch, Connector_Inhibot.kicad_sch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]
2026-09-30 Open KiCad
2026-10-04 début du placement
    [1ST_Schematix.kicad_pcb]
2026-10-05 début du routing
    [1ST_Schematix.kicad_pcb, 1ST_Schematix.kicad_sch, CPU_Inhibot.kicad_sch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]
2026-10-05 routage à faire vérifier
    [1ST_Schematix.kicad_pcb, 1ST_Schematix.kicad_sch, CPU_Inhibot.kicad_sch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]
2026-10-07 fin du routage, plus qu'à faire le jlcpb
    [1ST_Schematix-B_Cu.gbr, 1ST_Schematix-B_Mask.gbr, 1ST_Schematix-B_Paste.gbr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]
2026-10-08 gerber and starting jlcpcb
    [1ST_Schematix-B_Cu.gbr, 1ST_Schematix-B_Mask.gbr, 1ST_Schematix-B_Paste.gbr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]
2026-10-08 commande ready
    [1ST_Schematix-B_Cu.gbr, 1ST_Schematix-B_Mask.gbr, 1ST_Schematix-B_Paste.gbr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]
2026-10-08 maj pour Mr Fiack
    [BOM.csv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]
2026-10-12 Model 3D PCB
2026-10-19 Datasheet + Ouverture Kicad

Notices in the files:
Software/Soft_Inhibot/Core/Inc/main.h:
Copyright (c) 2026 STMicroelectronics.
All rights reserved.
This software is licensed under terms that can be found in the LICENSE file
